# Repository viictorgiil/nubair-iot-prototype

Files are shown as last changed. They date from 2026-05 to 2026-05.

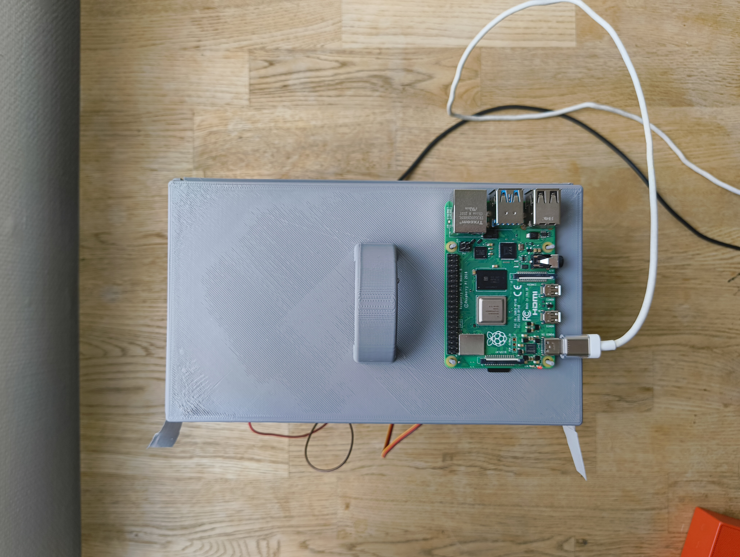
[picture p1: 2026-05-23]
docs/images/Vista_Superior.jpg

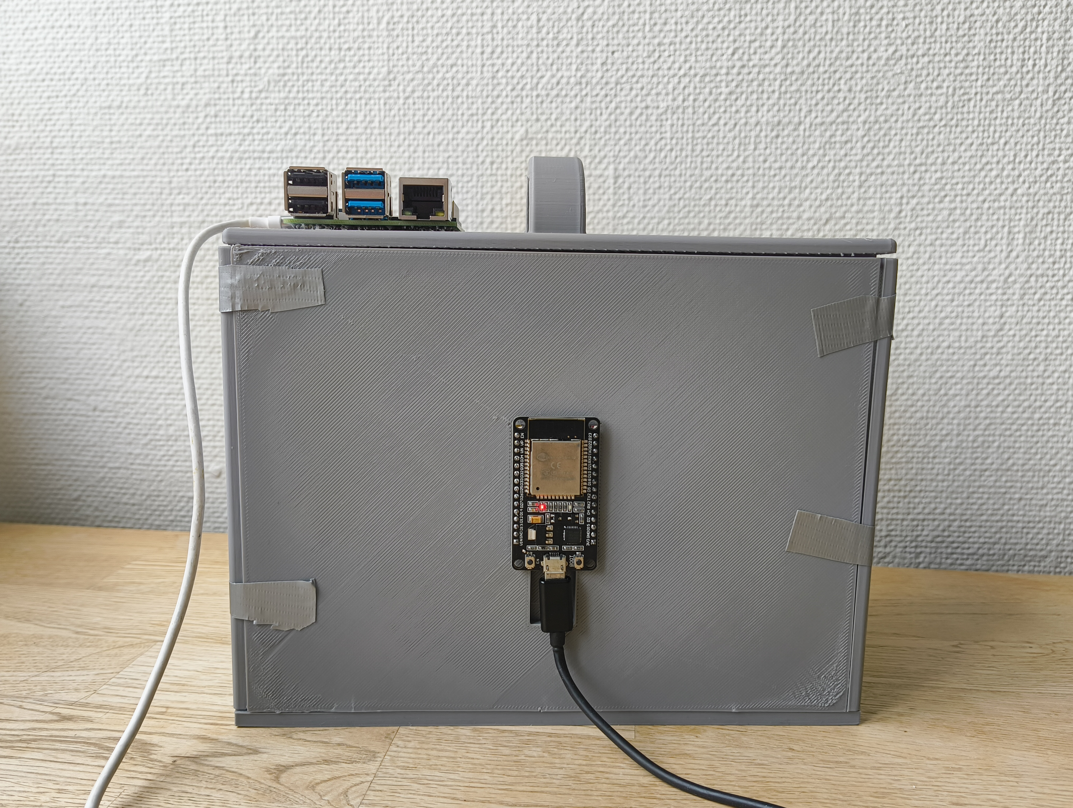
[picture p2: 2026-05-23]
docs/images/Vista_Lateral(ESP32).jpg

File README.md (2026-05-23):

# NUBAIR – IoT Prototype: Occupancy Monitoring & Door Control









> **Technical collaboration** for a seed-stage startup developing private rest modules for airports.  
> My scope: IoT firmware, server infrastructure, and physical prototype.

---

## Overview

NUBAIR cabins are modular rest pods designed to be installed in airports. This repository contains the full technical implementation of the IoT MVP prototype built to validate the concept:

- A physical **1:12 scale prototype** 3D-printed in modular sections
- An **ESP32** managing all sensors and actuators
- A **Raspberry Pi 4B** running Mosquitto (MQTT broker) and Home Assistant in Docker
- A **Home Assistant dashboard** showing the cabin image with an interactive door button

```
ESP32  <──WiFi/MQTT──>  Mosquitto  <──MQTT──>  Home Assistant
```

---

## My Responsibilities

- **3D CAD design** of the physical cabin prototype (OnShape, modular structure, 3D printed)
- **Server setup** on Raspberry Pi 4B (OS, SSH, static IP, Docker)
- **Mosquitto + Home Assistant** deployment via Docker Compose
- **ESP32 firmware** — sensors, servo, FSM logic, MQTT integration
- **Home Assistant dashboard** — cabin image with interactive door icon overlay
- **Full system integration testing**

---

## Repository Structure

```
nubair-iot-prototype/
│
├── firmware/
│   ├── nubair_proto_standalone/      # Standalone: all hardware, no WiFi/MQTT
│   │   └── nubair_proto_standalone.ino
│   │
│   └── nubair_proto_mqtt/            # Full version: WiFi + MQTT + Home Assistant
│       ├── nubair_proto_mqtt.ino
│       └── secrets.h.example         # Copy to secrets.h and fill in your values
│
├── server/
│   ├── docker-compose.yml            # Mosquitto + Home Assistant
│   └── mosquitto/
│       └── config/
│           └── mosquitto.conf
│
├── docs/
│   └── images/                       # Diagrams, screenshots, prototype photos
│
├── cad/
│   └── stl/                          # STL files to print
|
|
└── .gitignore
```

---

## Hardware

| Component | Model | Role |
|---|---|---|
| Microcontroller | ESP32 (38-pin) | Main controller |
| Servo | Standard 5V servo | Door mechanism |
| Touch sensor | TTP223 | Door open trigger (inside cabin) |
| Ultrasonic sensor | HC-SR04 | Presence detection |
| Display | SSD1306 OLED 128×64 | Status display (I2C) |
| Buzzer | Passive buzzer | Audio feedback |
| Server | Raspberry Pi 4B | MQTT broker + Home Assistant |

### Pin Map

| Pin | Component |
|---|---|
| GPIO 13 | Servo signal |
| GPIO 27 | Touch sensor (TTP223) |
| GPIO 5  | HC-SR04 TRIG |
| GPIO 18 | HC-SR04 ECHO |
| GPIO 25 | Buzzer |
| GPIO 21 | OLED SDA (I2C) |
| GPIO 22 | OLED SCL (I2C) |

---

## Firmware

### Phase 1 — Standalone (`nubair_proto_standalone`)

Used to validate all hardware before introducing network complexity.

**State machine logic:**

- OLED shows real-time distance readings from the ultrasonic sensor
- Holding the touch sensor for **3 seconds** triggers `openDoor()`
- Door stays open for **5 seconds**, then auto-closes
- Buzzer plays a melody on open, a short beep on close

### Phase 2 — MQTT (`nubair_proto_mqtt`)

Adds WiFi connectivity and full MQTT integration.

**MQTT topics:**

| Topic | Direction | Payload |
|---|---|---|
| `esp32/status` | ESP32 → broker | `online` / `offline` (LWT) |
| `esp32/door/state` | ESP32 → broker | `OPEN` / `CLOSED` |
| `esp32/door/set` | broker → ESP32 | `OPEN` / `CLOSE` |
| `esp32/distance/state` | ESP32 → broker | distance in cm |

**Setup:**

1. Copy `secrets.h.example` → `secrets.h`
2. Fill in your WiFi SSID, password, and Raspberry Pi IP
3. Flash to ESP32 via Arduino IDE

> **Note:** The ESP32 must connect to a **2.4 GHz** WiFi network. 5 GHz is not supported by the ESP32.

**Libraries required (Arduino IDE Library Manager):**

- `Adafruit GFX Library`
- `Adafruit SSD1306`
- `ESP32Servo`
- `PubSubClient`

---

## Server Setup (Raspberry Pi 4B)

### Prerequisites

- Raspberry Pi OS Lite 64-bit
- Docker installed (see below)
- Static IP configured via NetworkManager

### Deploy

```bash
# Clone the repo on the Raspberry Pi
git clone https://github.com/YOUR_USERNAME/nubair-iot-prototype.git
cd nubair-iot-prototype/server

# Create required directories
mkdir -p mosquitto/{data,log}

# Start services
docker compose up -d

# Verify
docker ps
```

Mosquitto will be available on port `1883`. Home Assistant on port `8123`.

### Install Docker (Raspberry Pi)

```bash
sudo install -m 0755 -d /etc/apt/keyrings
curl -fsSL https://download.docker.com/linux/debian/gpg | sudo tee /etc/apt/keyrings/docker.asc > /dev/null
sudo chmod a+r /etc/apt/keyrings/docker.asc

echo \
  "deb [arch=$(dpkg --print-architecture) signed-by=/etc/apt/keyrings/docker.asc] https://download.docker.com/linux/debian \
  $(. /etc/os-release && echo "$VERSION_CODENAME") stable" | \
  sudo tee /etc/apt/sources.list.d/docker.list > /dev/null

sudo apt update
sudo apt install -y docker-ce docker-ce-cli containerd.io docker-buildx-plugin docker-compose-plugin

sudo usermod -aG docker $USER
```

### MQTT Discovery for Home Assistant

Run this once to register the door switch entity in Home Assistant automatically:

```bash
docker exec -i nubair-mosquitto mosquitto_pub \
  -h localhost \
  -t "homeassistant/switch/nubair_door/config" \
  -r \
  -m '{
    "name": "Puerta Nubair",
    "unique_id": "nubair_esp32_door",
    "command_topic": "esp32/door/set",
    "state_topic": "esp32/door/state",
    "payload_on": "OPEN",
    "payload_off": "CLOSE",
    "state_on": "OPEN",
    "state_off": "CLOSED",
    "availability_topic": "esp32/status",
    "payload_available": "online",
    "payload_not_available": "offline",
    "device": {
      "identifiers": ["nubair_esp32"],
      "name": "Nubair ESP32",
      "manufacturer": "Nubair",
      "model": "ESP32 Door Controller"
    }
  }'
```

This must be run every time the Server is restarted. For a permament and future configuration, this will be changed.

### Home Assistant Dashboard Card

The dashboard uses a `picture-elements` card with the cabin image as background and an interactive icon positioned over the door:

```yaml
type: picture-elements
elements:
  - type: state-icon
    entity: switch.nubair_esp32_puerta_nubair
    icon: mdi:door
    tap_action:
      action: toggle
    hold_action:
      action: none
    style:
      top: 75%
      left: 15%
      transform: translate(-50%, -50%) scale(2)
      "--state-icon-color": black
image: /local/cabina.png
```

---

## Testing

### Test MQTT from the Raspberry Pi

```bash
# Subscribe to all ESP32 topics
docker exec -it nubair-mosquitto mosquitto_sub -h localhost -t "esp32/#" -v

# Manually open the door
docker exec -it nubair-mosquitto mosquitto_pub -h localhost -t "esp32/door/set" -m "OPEN"

# Manually close the door
docker exec -it nubair-mosquitto mosquitto_pub -h localhost -t "esp32/door/set" -m "CLOSE"
```

### Check Mosquitto logs

```bash
docker logs nubair-mosquitto --tail=30
```

---

## Physical Prototype

The cabin enclosure was designed in **OnShape** as a modular assembly and 3D-printed in PLA.

The electronics were installed inside the prototype to validate:
- Sensor placement and wiring
- Servo actuation of the door mechanism
- OLED visibility from inside the cabin

> **Known limitations of current prototype:** The ultrasonic sensor and servo mounting are provisional. The servo is not yet mechanically coupled to the door in a way that produces reliable actuation. These are hardware integration tasks pending for the next iteration.

*Photos and CAD exports in `docs/images/`.*

---

## Security Notes

The current Mosquitto configuration uses `allow_anonymous true` for ease of development. Before any production or public deployment:

1. Disable anonymous access in `mosquitto.conf`:
```conf
allow_anonymous false
password_file /mosquitto/config/passwordfile
```

2. Create MQTT users:
```bash
docker exec -it nubair-mosquitto mosquitto_passwd -c /mosquitto/config/passwordfile homeassistant
docker exec -it nubair-mosquitto mosquitto_passwd /mosquitto/config/passwordfile esp32
```

3. Update Home Assistant MQTT integration and ESP32 firmware accordingly.

---

## Roadmap

> This prototype represents a **Beta phase** focused on validating the core concept. The following work is pending for the next iteration.

### Hardware

- Proper mechanical coupling of the servo to the door mechanism
- Fixed mounting of the ultrasonic sensor at the correct angle and distance
- Clean wiring and cable management inside the cabin enclosure
- Improve the 3D Design by making the joints more robust

### Firmware & Logic

- Automatic occupancy state management based on sensor readings, removing the need for manual MQTT commands
- Finite state machine extended with states: `AVAILABLE`, `OCCUPIED`, `DOOR_OPENING`, `DOOR_CLOSING`

### Backend

- Lightweight database (SQLite or InfluxDB) to log occupancy events
- Records: user identifier, entry timestamp, exit timestamp, session duration
- REST API or MQTT-to-DB bridge running on the Raspberry Pi

### Dashboard

- Occupancy history view in Home Assistant or a dedicated web interface
- Real-time session timer visible while the cabin is in use

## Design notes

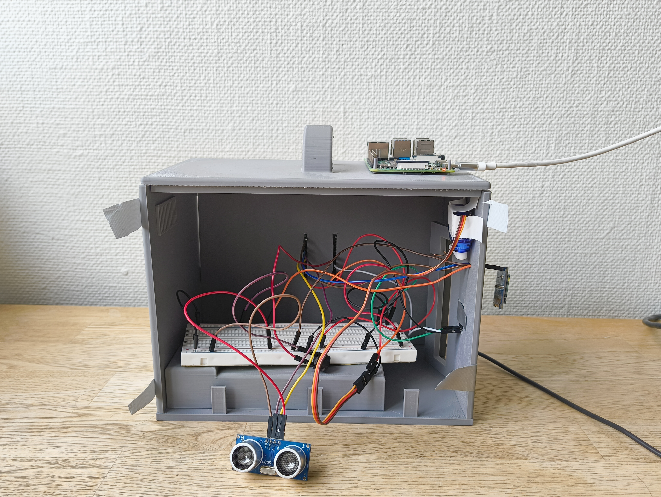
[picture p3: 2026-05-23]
docs/images/Vista_Lateral(open).jpg

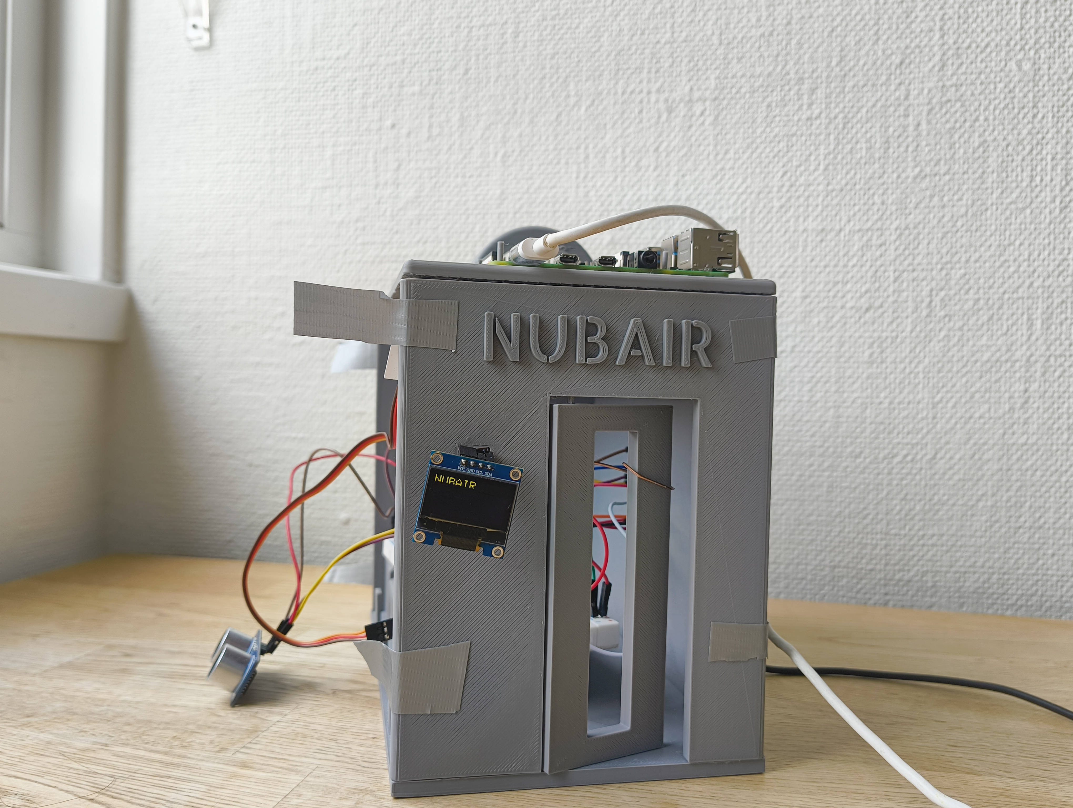
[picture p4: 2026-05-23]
docs/images/Vista_Frontal.jpg

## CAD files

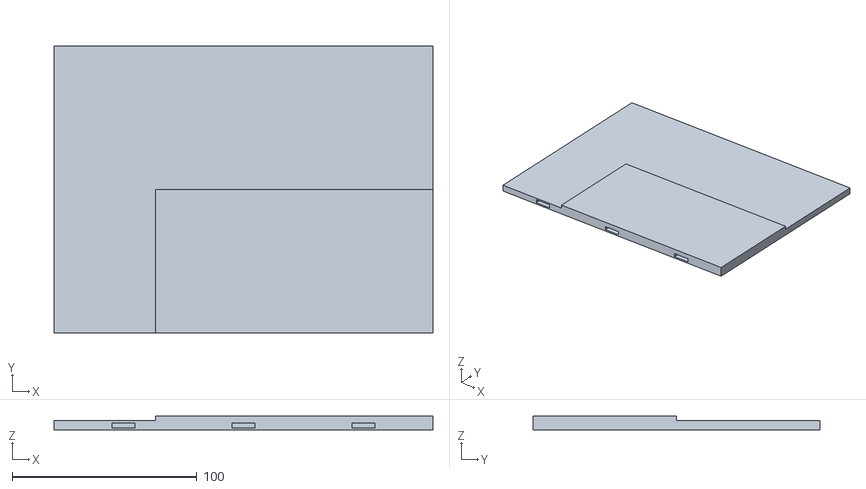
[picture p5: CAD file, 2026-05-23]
cad/stl/Pared lateral 1.stl
205.0 x 155.0 x 7.50

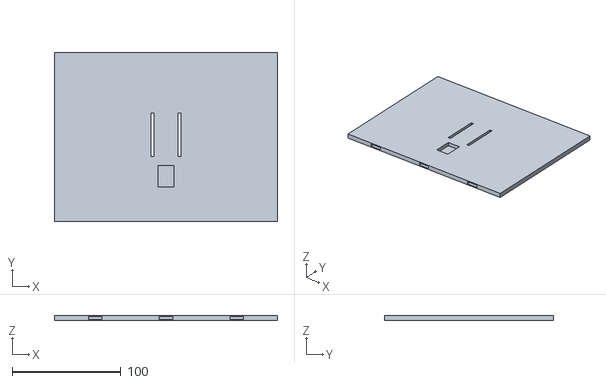
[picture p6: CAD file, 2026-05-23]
cad/stl/Pared lateral ESP32.stl
205.0 x 155.0 x 5.00

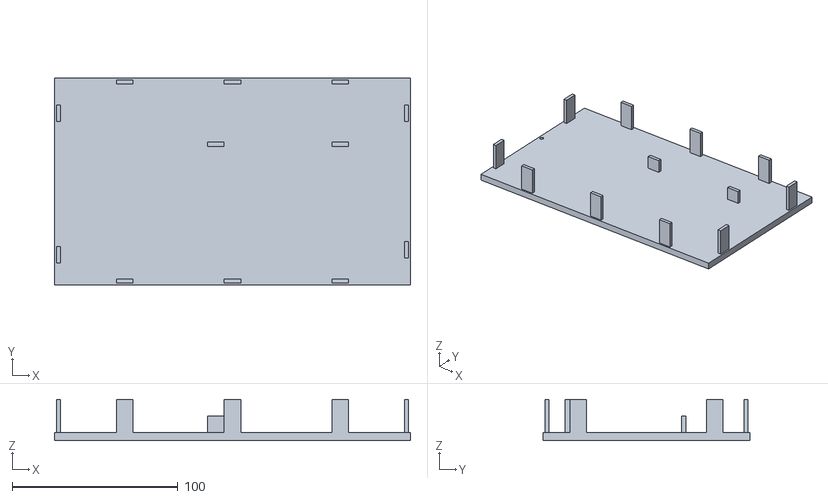
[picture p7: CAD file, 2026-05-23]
cad/stl/Base.stl
215.0 x 125.0 x 25.0

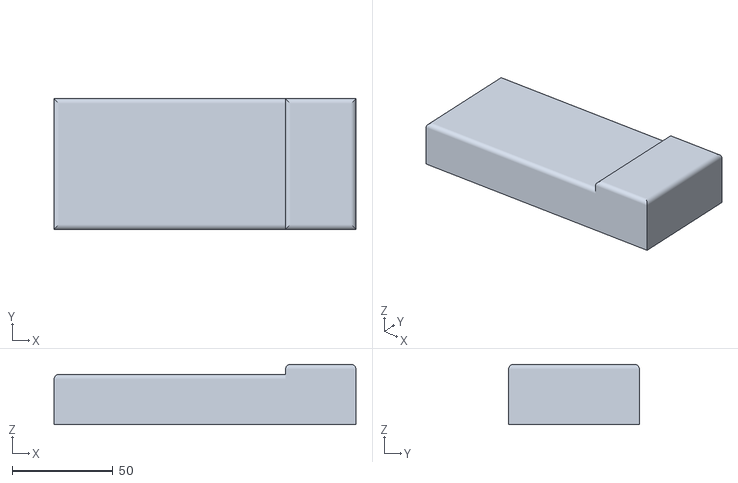
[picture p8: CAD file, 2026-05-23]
cad/stl/Cama.stl
150.0 x 65.0 x 30.0

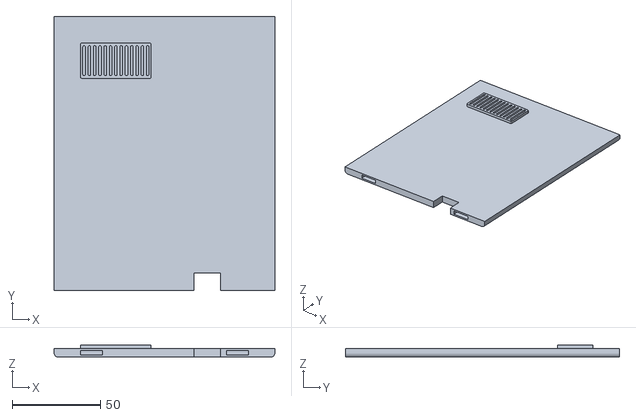
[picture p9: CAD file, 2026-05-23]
cad/stl/Pared trasera.stl
125.0 x 155.0 x 7.00

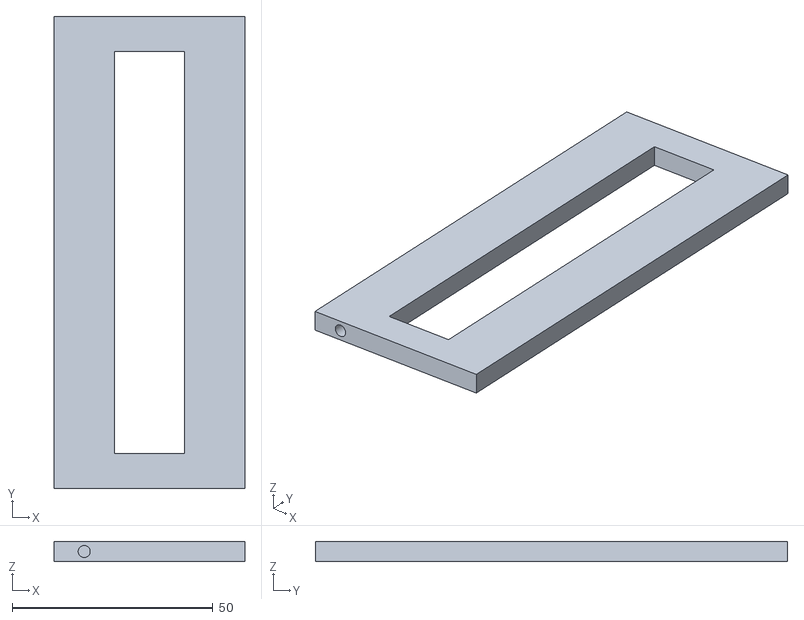
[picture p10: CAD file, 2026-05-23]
cad/stl/Puerta.stl
47.5 x 117.5 x 5.00

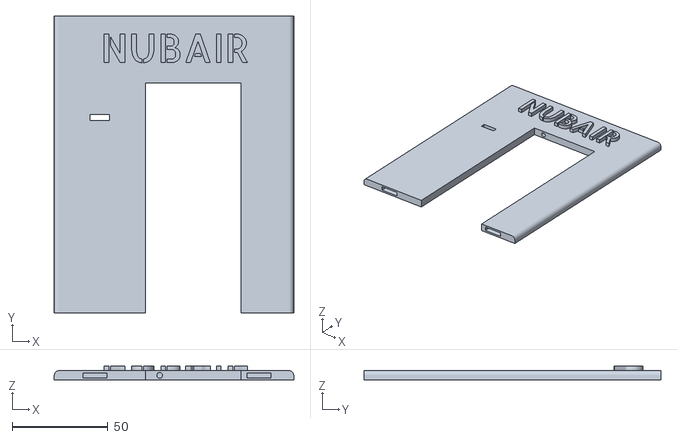
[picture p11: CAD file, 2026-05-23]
cad/stl/Pared delantera.stl
125.0 x 155.0 x 7.50

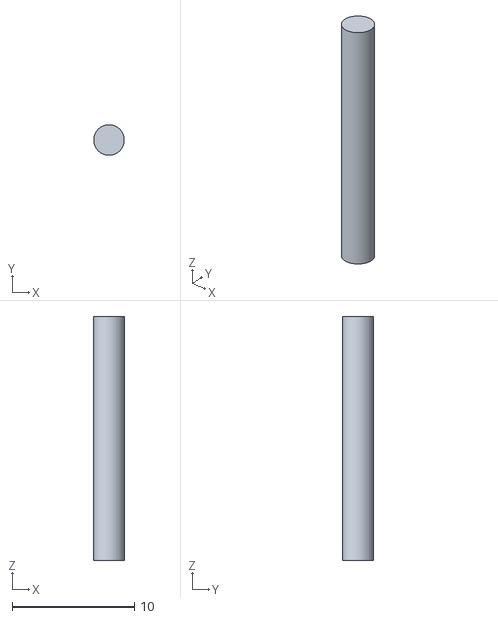
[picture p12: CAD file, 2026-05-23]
cad/stl/Eje puerta.stl
2.50 x 2.50 x 20.0

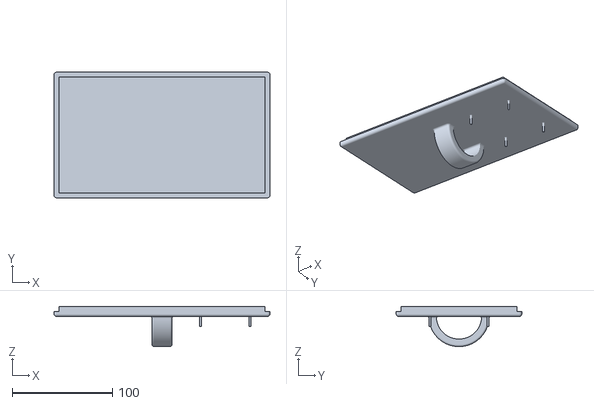
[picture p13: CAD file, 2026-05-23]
cad/stl/Techo.stl
215.0 x 125.0 x 40.0

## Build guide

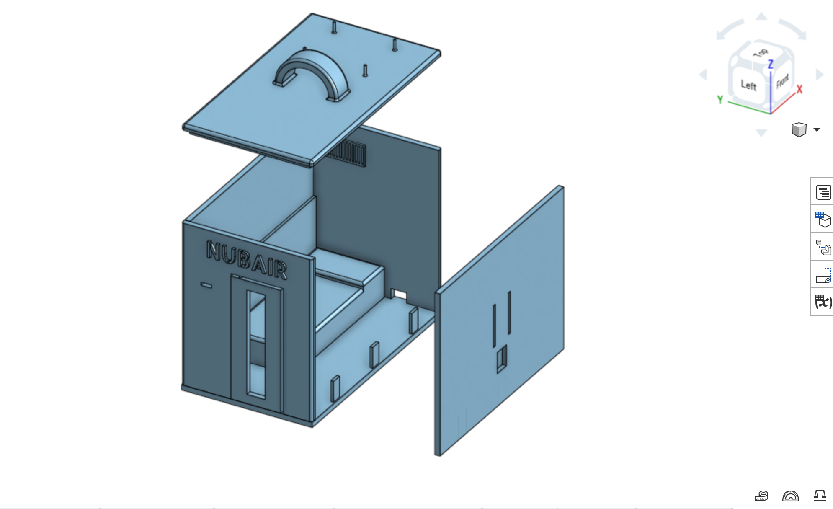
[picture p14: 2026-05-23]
docs/images/Assembly.png

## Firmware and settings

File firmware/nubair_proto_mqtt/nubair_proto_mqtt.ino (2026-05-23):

/*
 * NUBAIR - Firmware con MQTT
 * 
 * Firmware principal del prototipo ESP32 con conectividad WiFi y MQTT.
 * Integra el control de puerta con el broker Mosquitto corriendo en
 * Docker en la Raspberry Pi, y expone las entidades en Home Assistant.
 * 
 * Hardware:
 *   - ESP32
 *   - Servo (pin 13)
 *   - Sensor táctil TTP223 (pin 27)
 *   - Sensor ultrasónico HC-SR04 (TRIG: 5, ECHO: 18)
 *   - Buzzer pasivo (pin 25)
 *   - Pantalla OLED SSD1306 128x64 por I2C (SDA: 21, SCL: 22)
 * 
 * Librerías necesarias:
 *   - Adafruit GFX Library
 *   - Adafruit SSD1306
 *   - ESP32Servo
 *   - PubSubClient
 * 
 * Configuración:
 *   - Renombrar secrets.h.example → secrets.h y rellenar con tus valores
 *   - El ESP32 debe conectarse a la red WiFi de 2.4 GHz
 *   - El broker MQTT (Mosquitto) debe estar accesible en la IP configurada
 * 
 * Topics MQTT:
 *   esp32/status          → publica "online" / "offline" (LWT)
 *   esp32/door/state      → publica "OPEN" / "CLOSED"
 *   esp32/door/set        → escucha "OPEN" / "CLOSE"
 *   esp32/distance/state  → publica distancia en cm
 */

#include <Wire.h>
#include <Adafruit_GFX.h>
#include <Adafruit_SSD1306.h>
#include <ESP32Servo.h>
#include <WiFi.h>
#include <PubSubClient.h>

#include "secrets.h"  // WIFI_SSID, WIFI_PASSWORD, MQTT_SERVER

// -----------------------------
// MQTT
// -----------------------------
const int mqtt_port = 1883;

WiFiClient   espClient;
PubSubClient mqttClient(espClient);

const char* TOPIC_STATUS         = "esp32/status";
const char* TOPIC_DOOR_SET       = "esp32/door/set";
const char* TOPIC_DOOR_STATE     = "esp32/door/state";
const char* TOPIC_DISTANCE_STATE = "esp32/distance/state";

// -----------------------------
// OLED
// -----------------------------
#define SCREEN_WIDTH 128
#define SCREEN_HEIGHT 64
#define OLED_ADDR 0x3C

Adafruit_SSD1306 display(SCREEN_WIDTH, SCREEN_HEIGHT, &Wire, -1);

const int OLED_SDA = 21;
const int OLED_SCL = 22;

// -----------------------------
// Pines
// -----------------------------
const int SERVO_PIN  = 13;
const int TOUCH_PIN  = 27;
const int TRIG_PIN   = 5;
const int ECHO_PIN   = 18;
const int BUZZER_PIN = 25;

// -----------------------------
// Servo
// -----------------------------
Servo doorServo;

const int SERVO_CLOSED_ANGLE = 0;
const int SERVO_OPEN_ANGLE   = 90;

// -----------------------------
// Tiempos
// -----------------------------
const unsigned long TOUCH_HOLD_TIME = 3000;
const unsigned long DOOR_OPEN_TIME  = 5000;

unsigned long touchStartTime  = 0;
unsigned long doorOpenedTime  = 0;

bool touchWasActive         = false;
bool doorIsOpen             = false;
bool actionAlreadyTriggered = false;

// -----------------------------
// Ultrasonidos
// -----------------------------
unsigned long lastDistanceRead       = 0;
const unsigned long DISTANCE_INTERVAL = 500;

float lastDistanceCm = -1;

const float PRESENCE_DISTANCE_CM = 20.0;

unsigned long lastMqttDistancePublish       = 0;
const unsigned long MQTT_DISTANCE_INTERVAL  = 2000;

// -----------------------------
// Sensor táctil
// -----------------------------
const int TOUCH_ACTIVE_STATE = HIGH;

// -----------------------------
// Funciones auxiliares
// -----------------------------
void beep(int frequency, int durationMs) {
  tone(BUZZER_PIN, frequency, durationMs);
}

void happySound() {
  tone(BUZZER_PIN, 988,  100); delay(120);
  tone(BUZZER_PIN, 1319, 100); delay(120);
  tone(BUZZER_PIN, 1568, 130); delay(150);
  tone(BUZZER_PIN, 2093, 180); delay(200);
  noTone(BUZZER_PIN);
}

void showOLED(const String& line1, const String& line2 = "", const String& line3 = "") {
  display.clearDisplay();
  display.setTextColor(WHITE);

  display.setTextSize(2);
  display.setCursor(0, 0);
  display.println(line1);

  display.setTextSize(1);
  display.setCursor(0, 28);
  display.println(line2);

  display.setCursor(0, 42);
  display.println(line3);

  display.display();
}

float readDistanceCm() {
  digitalWrite(TRIG_PIN, LOW);
  delayMicroseconds(2);
  digitalWrite(TRIG_PIN, HIGH);
  delayMicroseconds(10);
  digitalWrite(TRIG_PIN, LOW);

  long duration = pulseIn(ECHO_PIN, HIGH, 30000);
  if (duration == 0) return -1;

  return duration * 0.0343 / 2.0;
}

// -----------------------------
// MQTT publish
// -----------------------------
void publishDoorState() {
  if (!mqttClient.connected()) return;
  mqttClient.publish(TOPIC_DOOR_STATE, doorIsOpen ? "OPEN" : "CLOSED", true);
}

void publishDistance() {
  if (!mqttClient.connected()) return;
  if (lastDistanceCm > 0) {
    String payload = String(lastDistanceCm, 1);
    mqttClient.publish(TOPIC_DISTANCE_STATE, payload.c_str(), true);
  }
}

// -----------------------------
// MQTT callback
// -----------------------------
void mqttCallback(char* topic, byte* message, unsigned int length) {
  String msg;
  for (unsigned int i = 0; i < length; i++) msg += (char)message[i];

  Serial.print("MQTT recibido [");
  Serial.print(topic);
  Serial.print("]: ");
  Serial.println(msg);

  if (String(topic) == TOPIC_DOOR_SET) {
    msg.toUpperCase();
    if (msg == "OPEN")  openDoor();
    if (msg == "CLOSE") closeDoor();
  }
}

// -----------------------------
// Conexión WiFi y MQTT
// -----------------------------
void conectarWiFi() {
  Serial.print("Conectando a WiFi...");
  WiFi.begin(WIFI_SSID, WIFI_PASSWORD);

  while (WiFi.status() != WL_CONNECTED) {
    delay(500);
    Serial.print(".");
  }

  Serial.println();
  Serial.print("WiFi conectado - IP: ");
  Serial.println(WiFi.localIP());
}

void conectarMQTT() {
  while (!mqttClient.connected()) {
    Serial.print("Conectando a MQTT... ");

    if (mqttClient.connect("esp32_nubair_01", TOPIC_STATUS, 0, true, "offline")) {
      Serial.println("conectado");

      mqttClient.publish(TOPIC_STATUS, "online", true);
      mqttClient.subscribe(TOPIC_DOOR_SET);

      publishDoorState();
      publishDistance();
    } else {
      Serial.print("falló rc=");
      Serial.print(mqttClient.state());
      Serial.println(", reintentando en 5 s...");
      delay(5000);
    }
  }
}

// -----------------------------
// Control de puerta
// -----------------------------
void openDoor() {
  doorServo.write(SERVO_OPEN_ANGLE);
  doorIsOpen     = true;
  doorOpenedTime = millis();

  happySound();

  Serial.println("Puerta abierta");
  showOLED("NUBAIR", "Puerta abierta", "Cerrando en 5 s");

  publishDoorState();
}

void closeDoor() {
  doorServo.write(SERVO_CLOSED_ANGLE);
  doorIsOpen             = false;
  actionAlreadyTriggered = false;
  touchWasActive         = false;
  touchStartTime         = 0;

  beep(800, 120);

  Serial.println("Puerta cerrada");
  showOLED("NUBAIR", "Puerta cerrada");

  publishDoorState();
}

// -----------------------------
// Manejadores de estado
// -----------------------------
void handleTouchSensor() {
  bool touchActive = digitalRead(TOUCH_PIN) == TOUCH_ACTIVE_STATE;

  if (touchActive && !touchWasActive) {
    touchStartTime = millis();
    touchWasActive = true;
    Serial.println("Toque detectado...");
    showOLED("NUBAIR", "Mantener 3 s", "para abrir");
  }

  if (!touchActive && touchWasActive) {
    touchWasActive = false;
    touchStartTime = 0;
    if (!doorIsOpen) {
      actionAlreadyTriggered = false;
      showOLED("NUBAIR", "Esperando toque");
    }
  }

  if (touchActive && touchWasActive && !doorIsOpen && !actionAlreadyTriggered) {
    if (millis() - touchStartTime >= TOUCH_HOLD_TIME) {
      actionAlreadyTriggered = true;
      openDoor();
    }
  }
}

void handleDoorAutoClose() {
  if (doorIsOpen && millis() - doorOpenedTime >= DOOR_OPEN_TIME) {
    closeDoor();
  }
}

void handleUltrasonic() {
  if (millis() - lastDistanceRead >= DISTANCE_INTERVAL) {
    lastDistanceRead = millis();
    lastDistanceCm   = readDistanceCm();

    if (lastDistanceCm > 0) {
      Serial.print("Distancia: "); Serial.print(lastDistanceCm); Serial.println(" cm");

      if (!doorIsOpen && !touchWasActive) {
        if (lastDistanceCm < PRESENCE_DISTANCE_CM)
          showOLED("NUBAIR", "Presencia cerca", String(lastDistanceCm, 1) + " cm");
        else
          showOLED("NUBAIR", "Esperando toque", String(lastDistanceCm, 1) + " cm");
      }
    } else {
      if (!doorIsOpen && !touchWasActive)
        showOLED("NUBAIR", "Sin lectura", "ultrasonidos");
    }
  }

  if (millis() - lastMqttDistancePublish >= MQTT_DISTANCE_INTERVAL) {
    lastMqttDistancePublish = millis();
    publishDistance();
  }
}

// -----------------------------
// Setup / Loop
// -----------------------------
void setup() {
  Serial.begin(115200);
  delay(500);
  Serial.println("\nIniciando prototipo NUBAIR (MQTT)...");

  pinMode(TOUCH_PIN,  INPUT);
  pinMode(TRIG_PIN,   OUTPUT);
  pinMode(ECHO_PIN,   INPUT);
  pinMode(BUZZER_PIN, OUTPUT);
  digitalWrite(TRIG_PIN, LOW);

  doorServo.setPeriodHertz(50);
  doorServo.attach(SERVO_PIN, 500, 2400);
  doorServo.write(SERVO_CLOSED_ANGLE);

  Wire.begin(OLED_SDA, OLED_SCL);
  if (!display.begin(SSD1306_SWITCHCAPVCC, OLED_ADDR)) {
    Serial.println("ERROR: pantalla OLED no detectada");
    while (true) { beep(400, 200); delay(1000); }
  }

  showOLED("NUBAIR", "Conectando WiFi");
  conectarWiFi();

  mqttClient.setServer(MQTT_SERVER, mqtt_port);
  mqttClient.setCallback(mqttCallback);

  conectarMQTT();

  showOLED("NUBAIR", "Sistema listo", "MQTT conectado");
  beep(1000, 100); delay(150); beep(1400, 100);
  Serial.println("Sistema listo");
}

void loop() {
  if (!mqttClient.connected()) conectarMQTT();
  mqttClient.loop();

  handleTouchSensor();
  handleDoorAutoClose();
  handleUltrasonic();
}
